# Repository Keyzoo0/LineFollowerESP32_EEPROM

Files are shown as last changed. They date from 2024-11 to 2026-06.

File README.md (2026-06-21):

<div align="center">

# 🤖 Robot Line Follower ESP32 — EEPROM Polinema

**Line follower kompetitif berbasis ESP32 dengan _path-programming on-device_, UI OLED non-blocking, dan 7 profil PID.**
Program lintasan langsung di robot — tanpa laptop, tanpa recompile.









</div>

---

> **🔧 Status:** firmware ini telah di-**refactor total** dari arsitektur _blocking_ menjadi **non-blocking
> (cooperative state machine)** dan dimigrasikan agar **compile bersih di Arduino-ESP32 core v3.x**.
> Diverifikasi dengan `arduino-cli compile` (0 error, 0 warning).

## ✨ Sorotan Fitur

- 🧠 **Path Programming (Plan → Index → Checkpoint)** — sampai **9 plan × 100 langkah**, tiap langkah punya 14 parameter (trigger sensor, aksi, kecepatan 2-fase, PID per-segmen, timer jarak-encoder).
- 🎛️ **UI OLED non-blocking** — navigasi tab/menu responsif, tanpa _freeze_, tanpa konflik antar-menu.
- 📏 **14 sensor IR** via 2× MUX, kalibrasi **auto & manual** + pengaturan sensitivitas.
- 🎚️ **7 profil PID** yang bisa di-tune & dites _live_ di robot.
- 🏁 **Checkpoint resume** + stopwatch waktu tempuh.
- ⚫⚪ **Garis hitam & putih** didukung dalam satu lookup-table, 3 mode follow (center/kanan/kiri).
- 🔋 **Proteksi baterai** (cutoff sebelum start) + indikator persen.
- 🧰 **Tools on-device**: Test Motor, Copy/Mirror Plan, Reset Plan, Set Default, Set Throttle.

---

## 📑 Daftar Isi
1. [Quick Start](#-quick-start)
2. [Hardware](#-hardware)
3. [Arsitektur Non-Blocking](#-arsitektur-non-blocking)
4. [Peta Menu](#-peta-menu)
5. [Path Programming](#-path-programming-planindexcheckpoint)
6. [Profil PID](#-profil-pid)
7. [Apa yang Berubah di Refactor Ini](#-apa-yang-berubah-di-refactor-ini)
8. [Peta Memori](#-peta-memori)
9. [Struktur Proyek](#-struktur-proyek)
10. [Roadmap](#-roadmap)
11. [Kredit & Lisensi](#-kredit--lisensi)

---

## 🚀 Quick Start

<details open>
<summary><b>Build via arduino-cli (cara yang dipakai untuk verifikasi)</b></summary>

```bash
# 1. Pasang core ESP32 v3.x
arduino-cli config add board_manager.additional_urls https://espressif.github.io/arduino-esp32/package_esp32_index.json
arduino-cli core update-index
arduino-cli core install esp32:esp32

# 2. Pasang library
arduino-cli lib install "Adafruit GFX Library" "Adafruit SH110X" "Adafruit PCF8574" "SPIMemory"

# 3. Compile
arduino-cli compile --fqbn esp32:esp32:esp32 LineFollowerESP32_EEPROM

# 4. Upload (ganti /dev/ttyUSB0 sesuai port)
arduino-cli upload  --fqbn esp32:esp32:esp32 -p /dev/ttyUSB0 LineFollowerESP32_EEPROM
```
</details>

<details>
<summary><b>Build via Arduino IDE</b></summary>

1. **Boards Manager** → pasang `esp32 by Espressif` (versi 3.x).
2. **Library Manager** → pasang: Adafruit GFX, Adafruit SH110X, Adafruit PCF8574, SPIMemory.
3. Buka folder `LineFollowerESP32_EEPROM/`, pilih board **ESP32 Dev Module**, lalu Upload.
</details>

> ⚠️ **Setelah flash pertama**, jalankan menu **Settings → Set Default** sekali untuk menginisialisasi
> layout memori baru (`VAL_INDEX` kini 100). Lalu **Calib Sensor → Auto** untuk kalibrasi lintasan.

---

## 🔩 Hardware

| Subsistem | Komponen | Pin / Alamat |
|---|---|---|
| **MCU** | ESP32 (240 MHz) | — |
| **Sensor garis** | 14× IR analog via 2× MUX 8-kanal (7 kiri + 7 kanan) | ADC `32` (kiri), `35` (kanan); selektor `13/14/15` |
| **Driver motor** | H-bridge (BTS7960), PWM LEDC 15 kHz / 8-bit | Kiri `26/27` · Kanan `17/16` |
| **Encoder** | 2× rotary quadrature (CPR 208, roda Ø17 mm) | Kiri `33/25` · Kanan `39/36` |
| **Display** | OLED SH1106 128×64 I²C | `0x3C` |
| **Tombol** | 6 tombol via PCF8574 (I²C expander) | `0x27` |
| **Memori lintasan** | SPI Flash Winbond 4MB (SPIMemory) | CS `5` |
| **Memori konfigurasi** | EEPROM emulasi 1 KB | — |
| **Baterai** | ADC + divider 10k/3.3k, filter EMA, cutoff 11.8 V | `34` |
| **LED status** | indikator tulis memori | `12` |

> PCB (KiCad) & model 3D tersedia di folder [`Electrical/`](Electrical) dan [`3d Model/`](3d%20Model).

---

## 🧩 Arsitektur Non-Blocking

Versi lama menjebak eksekusi di `while(1)` tiap menu (blocking) + tombol _busy-wait_ + state global dipakai
bersama → tidak responsif & sering konflik antar-menu. Versi ini memakai **loop kooperatif**:

```mermaid
flowchart LR
    L([loop]) --> I[inputUpdate<br/>baca 6 tombol sekali<br/>edge + auto-repeat]
    I --> H[uiHandle<br/>logika layar aktif]
    H --> F{sudah 33 ms?}
    F -- ya --> R[uiRender<br/>1x lcd.display per frame]
    F -- tidak --> L
    R --> L
```

**3 pilar yang menghilangkan blocking & konflik:**

| Pilar | Sebelum | Sesudah |
|---|---|---|
| **Input** | `touchUp()` _busy-wait_ menunggu tombol dilepas | `inputUpdate()` non-blocking → event `PRESS / HOLD / RELEASE` (debounce + auto-repeat berbasis `millis()`) |
| **Render** | `clearDisplay()/display()` berserak di tiap layar | satu `lcd.display()` per frame (~30 fps) |
| **State** | global `selectSet/countMenu/halIdx` dipakai bersama | tiap layar punya **struct state lokal** + **screen stack** (push/pop) |

Navigasi antar-layar memakai state machine + stack:

```mermaid
stateDiagram-v2
    [*] --> HOME
    HOME --> MENU: OK
    HOME --> SETINDEX: Set Plan
    HOME --> CHECKPOINT
    HOME --> CALIB
    HOME --> RACE: RUN (mode C)
    HOME --> TUNEPID: RUN (mode F)
    MENU --> SETTINGS
    MENU --> TUNEPID
    MENU --> TESTMOTOR
    MENU --> COPYMIRROR
    MENU --> RESETPLAN
    SETINDEX --> ADDREMOVE
    SETTINGS --> SETDEFAULT
    SETTINGS --> THROTTLE
    RACE --> RACE_RESULT
    RACE_RESULT --> HOME
```

> 🏁 **Mode balapan** sengaja tetap _tight loop_ real-time (deterministik untuk kontrol), namun tombol
> abort dibaca non-blocking dan **semua timing pakai `millis()`** (tanpa `delay()`), jadi abort tetap responsif.

---

## 🗺️ Peta Menu

<details open>
<summary><b>Pohon menu lengkap</b></summary>

```
HOME ── UP/DOWN pindah widget · RUN = mulai ──────────────────────────
├─ Mode C/F        C=Balapan, F=Tune PID   ·  OK → MAIN MENU
├─ Set Plan        pilih plan (1–9)         ·  OK → SET INDEX
├─ Normal Speed    ±5
├─ CHKPNT          OK → CHECKPOINT
└─ CALSEN          OK → CALIB SENSOR

MAIN MENU ── UP/DOWN · RUN = back ────────────────────────────────────
├─ Set Plan          OK → SET INDEX
├─ Calib Sensor      +:Auto   -:Manual
├─ Tuning PID        OK → TUNE PID
├─ Test Motor        OK → TEST MOTOR
├─ Copy Mirror Plan  OK → COPY/MIRROR
├─ Delete Plan       OK → RESET PLAN
└─ Settings          OK → SETTINGS (Set Default · Set Throttle)

SET INDEX ── editor langkah (list datar, 15 baris) ───────────────────
   Index · Trig SLog · Trig Logic · Action · Speed L/R · Act Delay ·
   PID Prof · Speed A · Timer A · Mode TIM · Speed B · Timer B ·
   UsedSens · FL Mode      (OK di baris "Index" → ADD/REMOVE langkah)
```
</details>

**Tombol:** `OK` pilih/masuk · `UP/DOWN` navigasi · `+ / -` ubah nilai (tahan = auto-repeat) · `RUN` kembali/mulai.

---

## 🧠 Path Programming (Plan/Index/Checkpoint)

Robot menjalankan **program lintasan** yang tersimpan, bukan sekadar mengikuti garis.

- **Plan** = satu lintasan penuh (ada **9** plan).
- **Index** = satu langkah dalam plan (ada **100** langkah/plan). Tiap langkah menyimpan:

| Parameter | Fungsi |
|---|---|
| `Trig SLog` + `Trig Logic` | **Pemicu**: pola sensor + logika `OR / AND / TIM / XOR` |
| `Action` | aksi saat terpicu: `STOP/FORWARD/LEFT/RIGHT/BACKWARD/PICK/DROP/TLEFT/TRIGHT/FAN` |
| `Speed L/R` + `Act Delay` | kecepatan & durasi aksi |
| `Speed A/B` + `Timer A/B` | **2 fase kecepatan** dengan ramp berbeda |
| `Mode TIM` | sumber timer: waktu `mS` atau **jarak encoder** `CmR/CmL` |
| `PID Prof` | profil PID per-segmen (Normal..Profil 6) |
| `UsedSens` | masking sensor pinggir (All / Ignore 1–3 sisi) |
| `FL Mode` | sisi garis: `FLC` center · `FLR` kanan · `FLL` kiri |

- **Checkpoint** = titik _resume_; robot bisa lanjut balapan dari langkah tertentu (8 CP/plan).

```mermaid
flowchart TD
    S[start] --> RD[baca sensor]
    RD --> TR{pemicu langkah<br/>terpenuhi?}
    TR -- tidak --> PID[ikuti garis PID<br/>normalSpeed] --> RD
    TR -- ya --> ACT[eksekusi Action] --> A[fase A: ramp ke Speed A<br/>selama Timer A]
    A --> B[fase B: ramp ke Speed B<br/>selama Timer B]
    B --> ST{langkah == stop?}
    ST -- tidak --> NX[langkah++] --> RD
    ST -- ya --> F([selesai: tampil waktu])
```

---

## 🎚️ Profil PID

7 profil tersimpan di EEPROM, di-tune lewat **Tuning PID** (+ uji _live_ "Coba PID"):

| Profil | Kp | Ki | Kd | Target v |
|:---:|:--:|:--:|:--:|:---:|
| Normal | 3.0 | 0.00 | 10 | 50 |
| Profil 1 | 7.0 | 0.02 | 12 | 80 |
| Profil 2 | 7.0 | 0.02 | 15 | 100 |
| Profil 3 | 7.4 | 0.04 | 35 | 120 |
| Profil 4 | 7.4 | 0.04 | 40 | 140 |
| Profil 5 | 7.4 | 0.04 | 50 | 160 |
| Profil 6 | 7.4 | 0.04 | 60 | 180 |

Hukum kontrol: `move = error·Kp + ΣError·Ki + Δerror·Kd` → `kiri = v − move`, `kanan = v + move` (clamp ±255).

---

## 🔄 Apa yang Berubah di Refactor Ini

<details>
<summary><b>🐞 Bug yang diperbaiki</b></summary>

| # | Bug | Perbaikan |
|---|-----|---|
| 1 | `VAL_INDEX=50` tapi UI memakai index 0–99 → **buffer overflow** | dinaikkan ke **100** + serialisasi flash diperbarui |
| 2 | Hanya 5 dari 9 plan dibaca saat boot (`readIdx` loop `<5`) | dimuat penuh `< VAL_PLAN` |
| 3 | `analogReadResolution(8)` vs kalibrasi skala 1023 | disamakan ke **10-bit** (battery ikut diperbaiki ÷1023) |
| 4 | `accelTA/accelTB` diatur tapi tak dipakai | kini **benar-benar dipakai** sebagai step ramp fase A/B |
| 5 | Transfer Plan tak terjangkau / stub | dihapus dari menu (out-of-scope) |
| 6 | `guiTestMotor` `speedsR == 255` (operator salah) | ditulis ulang dengan clamp benar |
| 7 | Duplikasi `struct Plan/CP` global (~15 KB) + bug sinkronisasi | dihapus, serialisasi via blob transien |

</details>

<details>
<summary><b>⚙️ Migrasi Arduino-ESP32 v3.x (LEDC)</b></summary>

| Lama (v2.x) | Baru (v3.x) |
|---|---|
| `ledcSetup(ch, freq, res)` + `ledcAttachPin(pin, ch)` | `ledcAttach(pin, freq, res)` |
| `ledcWrite(ch, duty)` | `ledcWrite(pin, duty)` |

Terisolasi di `motor.ino` — logika kontrol tidak berubah.
</details>

---

## 💾 Peta Memori

**EEPROM (1 KB)** — konfigurasi: home (0–3), sensitivity (4), max/min sensor (6–61), kalibrasi (62–89),
Kp/Ki/Kd (90–110), accel (111–112).

**SPI Flash 4MB** — lintasan: 9 plan × 1700 B + 9 checkpoint × 32 B ≈ **15.6 KB** (muat dalam `eraseBlock32K`).
Serialisasi memakai **blob transien** — tidak ada duplikasi RAM.

---

## 📂 Struktur Proyek

| Lapisan | File | Peran |
|---|---|---|
| **Entry** | `LineFollowerESP32_EEPROM.ino` | `setup()` + `loop()` (input → handle → render) |
| **Data** | `data.h`, `storage.ino` | konfigurasi, plan, checkpoint, save/load |
| **Input** | `input.h`, `input.ino` | tombol non-blocking (PCF8574) |
| **UI** | `ui.h`, `ui.ino` | state machine + dispatcher |
| **Layar** | `screens_main.ino`, `screens_index.ino`, `screens_tools.ino` | semua menu |
| **Kontrol** | `PID.ino`, `sensor.ino`, `motor.ino`, `encoder.ino`, `race.ino` | follow line + balapan |
| **Display** | `oled.h`, `oled.ino` | SH1106 + bitmap + helper gambar |
| **Util** | `timer.h` | stopwatch millis |

---

## 🛣️ Roadmap

Fitur berikut sengaja **di-tunda** (hardware belum ada / out-of-scope) agar fokus pada line follower:

- [ ] Transfer Plan (robot ↔ robot)
- [ ] Gripper & Fan (aksi `PICK/DROP/FAN` kini no-op)
- [ ] Setting Encoder (PID kecepatan)
- [ ] Wi-Fi + OTA Update
- [ ] Mode Transporter

---

## 🙏 Kredit & Lisensi

Dirancang oleh **Komunitas EEPROM Polinema** (tim G14/G15).
Refactor arsitektur non-blocking & migrasi core v3.x.

Lisensi **MIT** © 2024 [Keyzoo0](https://github.com/Keyzoo0) — lihat [LICENSE](LICENSE).

<div align="center">

⭐ _Kalau proyek ini membantu, kasih bintang ya!_ ⭐

</div>

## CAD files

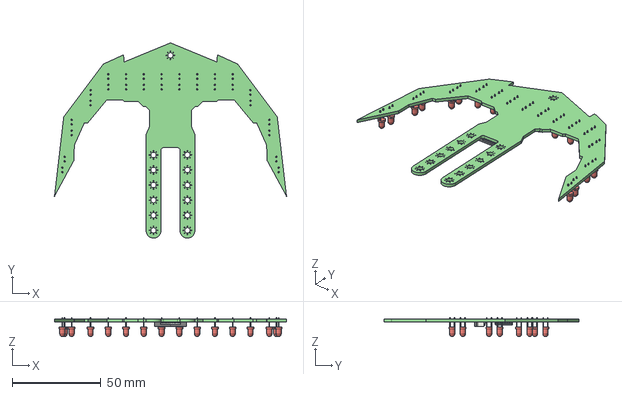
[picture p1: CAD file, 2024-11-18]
Electrical/Sensor_V2.1_2/Sensor_V2.1.step
130.6 x 109.9 x 10.8 mm
Sensor_V2.1 PCB

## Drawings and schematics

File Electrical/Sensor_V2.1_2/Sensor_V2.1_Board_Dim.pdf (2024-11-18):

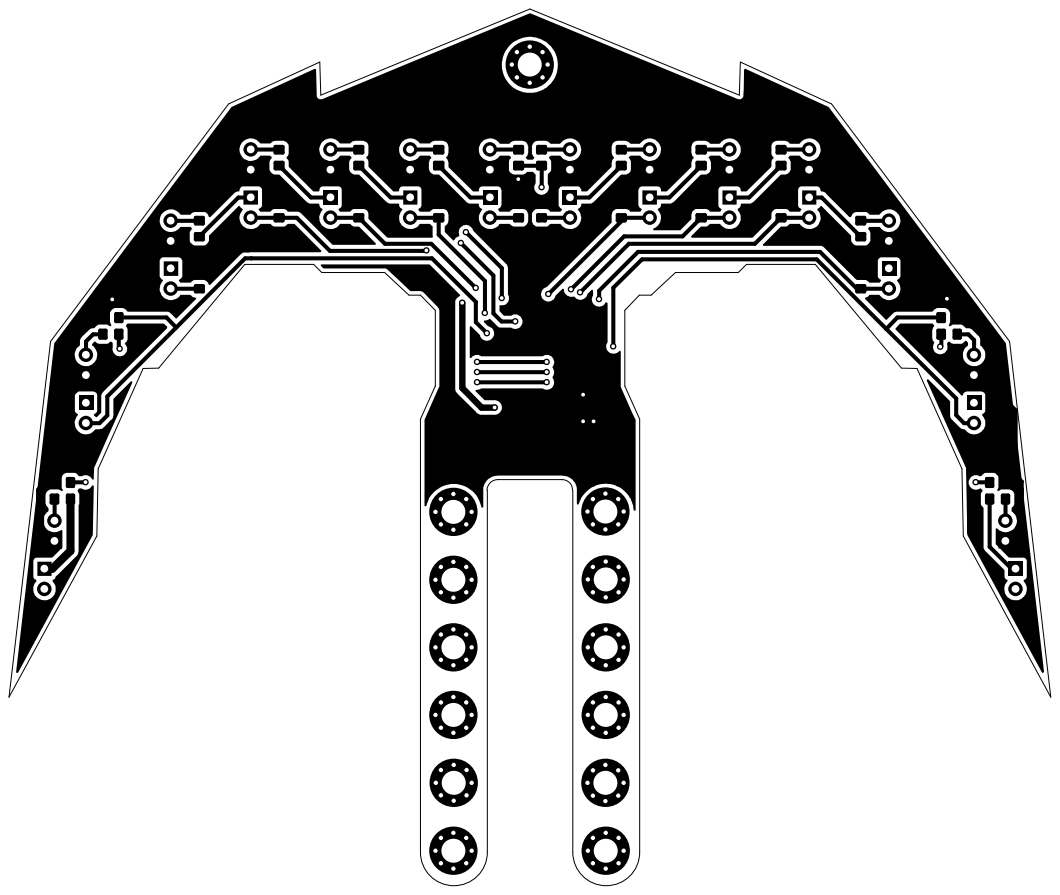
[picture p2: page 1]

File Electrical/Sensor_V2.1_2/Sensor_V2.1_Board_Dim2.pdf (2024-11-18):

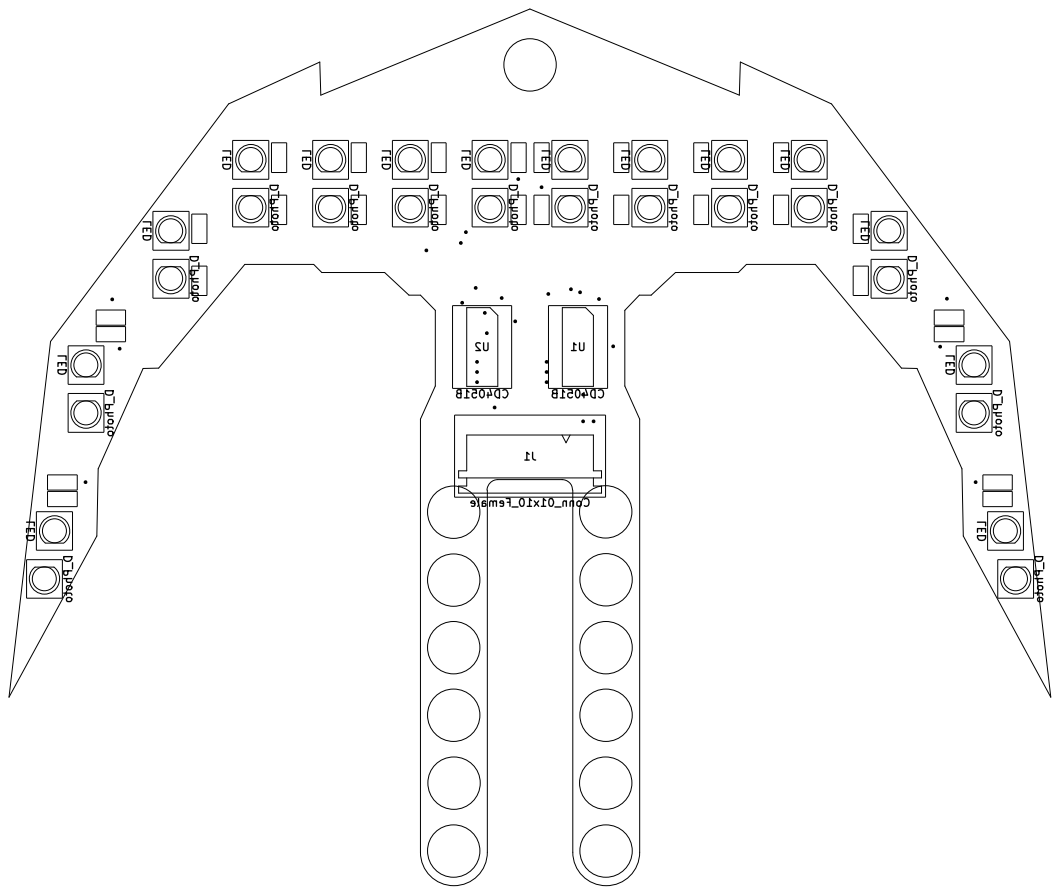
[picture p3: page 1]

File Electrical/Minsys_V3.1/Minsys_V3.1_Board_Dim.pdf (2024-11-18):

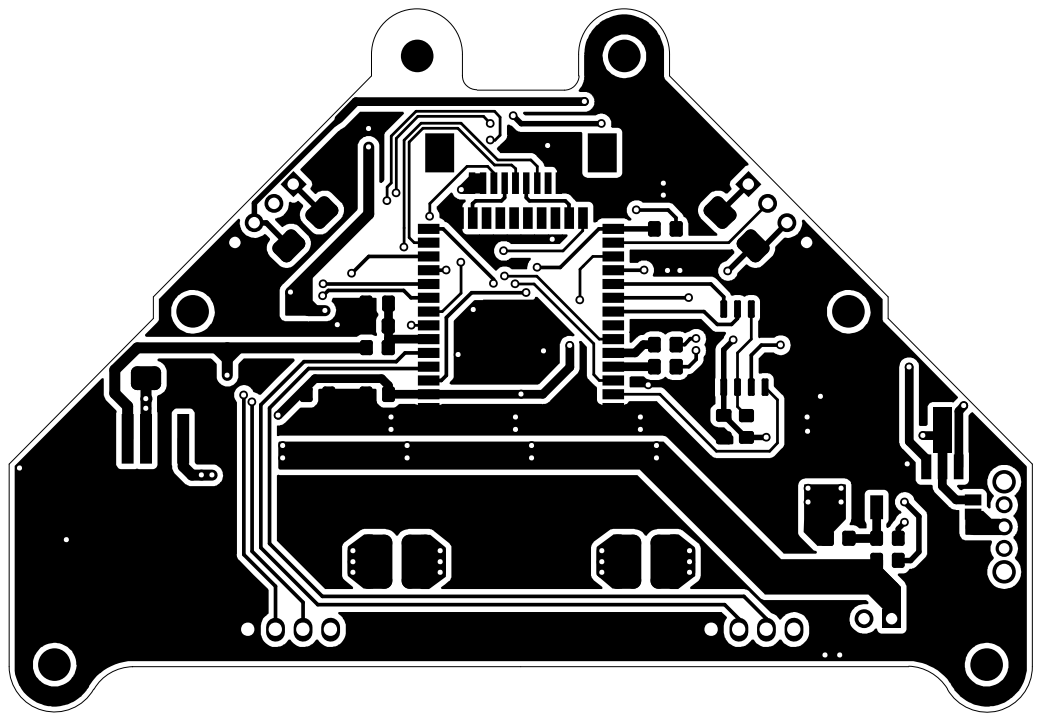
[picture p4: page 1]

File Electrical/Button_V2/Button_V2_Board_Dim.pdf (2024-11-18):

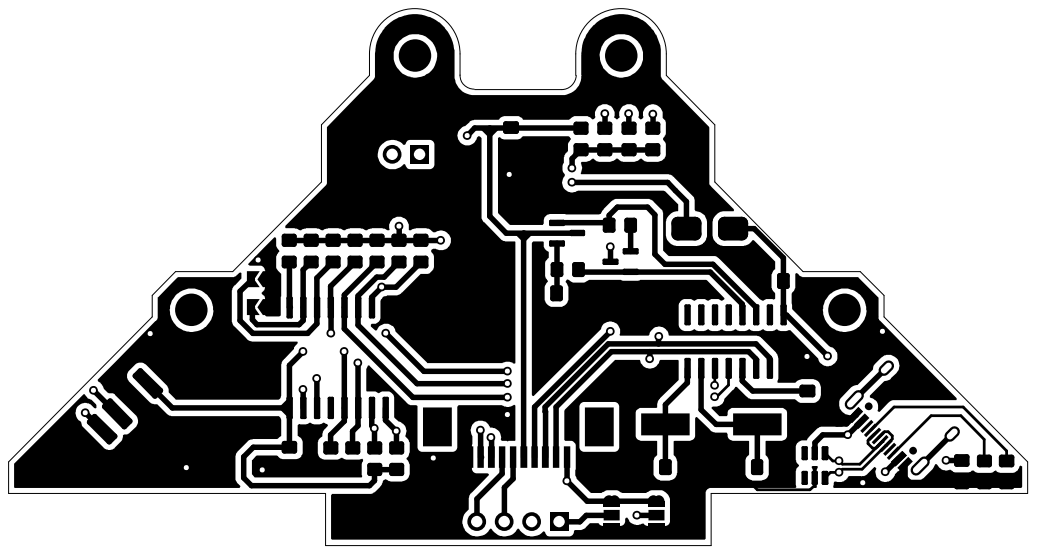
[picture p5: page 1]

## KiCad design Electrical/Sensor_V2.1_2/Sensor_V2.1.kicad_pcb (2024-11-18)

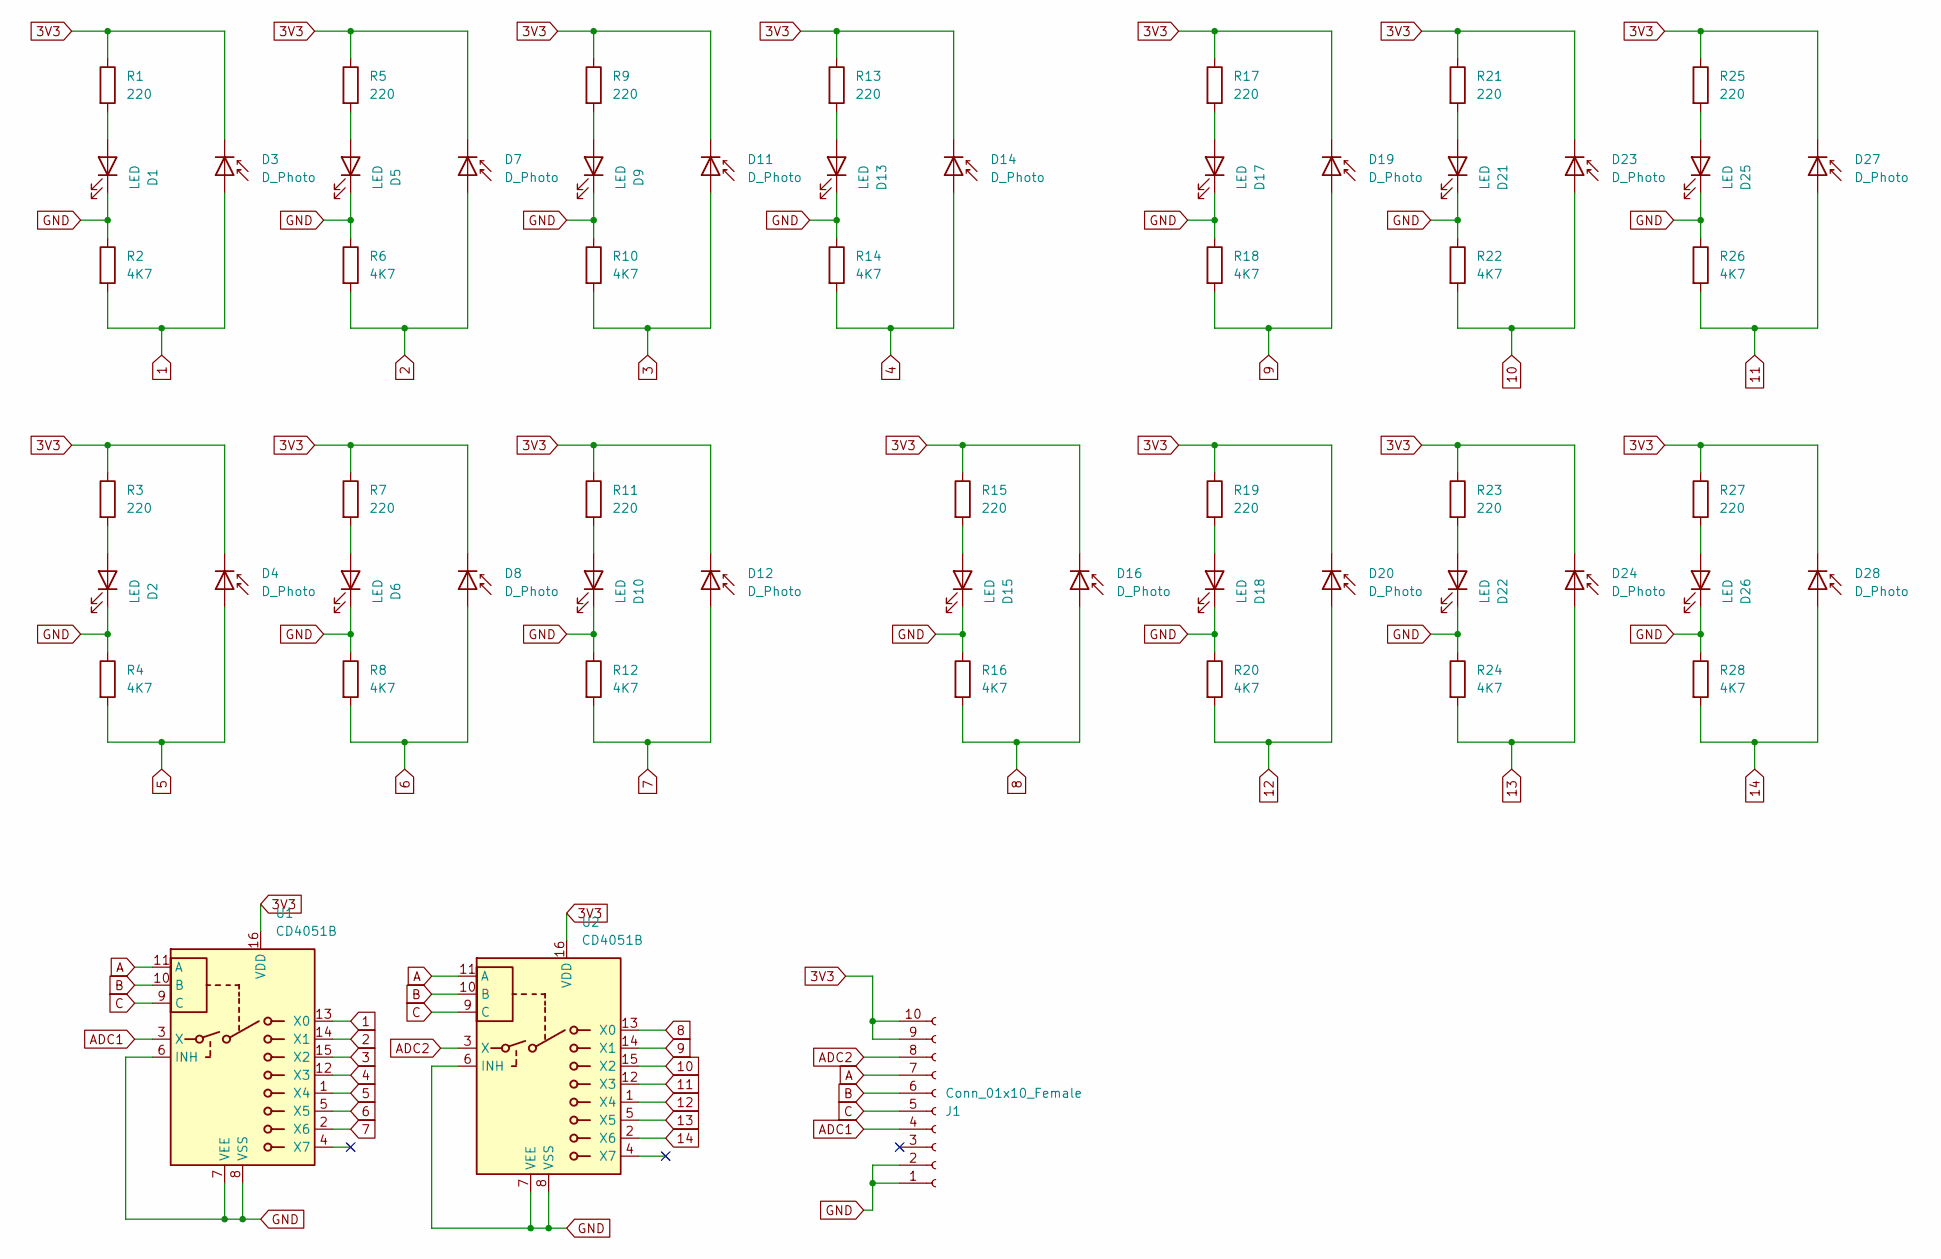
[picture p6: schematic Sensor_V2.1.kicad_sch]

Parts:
D1, D2, D5, D6, D9, D10, D13, D15, D17, D18, D21, D22, D25, D26: LED; LED_D3.0mm
D3, D4, D7, D8, D11, D12, D14, D16, D19, D20, D23, D24, D27, D28: D_Photo; LED_D3.0mm
J1: Conn_01x10_Female; TE_1-84952-0_1x10-1MP_P1.0mm_Horizontal
R1, R3, R5, R7, R9, R11, R13, R15, R17, R19, R21, R23, R25, R27: 220; R_0805_2012Metric_Pad1.20x1.40mm_HandSolder
R2, R4, R6, R8, R10, R12, R14, R16, R18, R20, R22, R24, R26, R28: 4K7; R_0805_2012Metric_Pad1.20x1.40mm_HandSolder
U1, U2: CD4051B; SOIC-16_3.9x9.9mm_P1.27mm

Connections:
1: D3.2 (A), R2.2, U1.13 (X0)
2: D7.2 (A), R6.2, U1.14 (X1)
3: D11.2 (A), R10.2, U1.15 (X2)
3V3: D3.1 (K), D4.1 (K), D7.1 (K), D8.1 (K), D11.1 (K), D12.1 (K), D14.1 (K), D16.1 (K), D19.1 (K), D20.1 (K), D23.1 (K), D24.1 (K), D27.1 (K), D28.1 (K), J1.9, J1.10, R1.1, R3.1, R5.1, R7.1, R9.1, R11.1, R13.1, R15.1, R17.1, R19.1, R21.1, R23.1, R25.1, R27.1, U1.16 (VDD), U2.16 (VDD)
4: D14.2 (A), R14.2, U1.12 (X3)
5: D4.2 (A), R4.2, U1.1 (X4)
6: D8.2 (A), R8.2, U1.5 (X5)
7: D12.2 (A), R12.2, U1.2 (X6)
8: D16.2 (A), R16.2, U2.13 (X0)
9: D19.2 (A), R18.2, U2.14 (X1)
10: D23.2 (A), R22.2, U2.15 (X2)
11: D27.2 (A), R26.2, U2.12 (X3)
12: D20.2 (A), R20.2, U2.1 (X4)
13: D24.2 (A), R24.2, U2.5 (X5)
14: D28.2 (A), R28.2, U2.2 (X6)
A: J1.7, U1.11 (A), U2.11 (A)
ADC1: J1.4, U1.3 (X)
ADC2: J1.8, U2.3 (X)
B: J1.6, U1.10 (B), U2.10 (B)
C: J1.5, U1.9 (C), U2.9 (C)
GND: D1.1 (K), D2.1 (K), D5.1 (K), D6.1 (K), D9.1 (K), D10.1 (K), D13.1 (K), D15.1 (K), D17.1 (K), D18.1 (K), D21.1 (K), D22.1 (K), D25.1 (K), D26.1 (K), J1.1, J1.2, R2.1, R4.1, R6.1, R8.1, R10.1, R12.1, R14.1, R16.1, R18.1, R20.1, R22.1, R24.1, R26.1, R28.1, U1.6 (INH), U1.7 (VEE), U1.8 (VSS), U2.6 (INH), U2.7 (VEE), U2.8 (VSS)
unnamed: D1.2 (A), R1.2
unnamed: D2.2 (A), R3.2
unnamed: D5.2 (A), R5.2
unnamed: D6.2 (A), R7.2
unnamed: D9.2 (A), R9.2
unnamed: D10.2 (A), R11.2
unnamed: D13.2 (A), R13.2
unnamed: D15.2 (A), R15.2
unnamed: D17.2 (A), R17.2
unnamed: D18.2 (A), R19.2
unnamed: D21.2 (A), R21.2
unnamed: D22.2 (A), R23.2
unnamed: D25.2 (A), R25.2
unnamed: D26.2 (A), R27.2

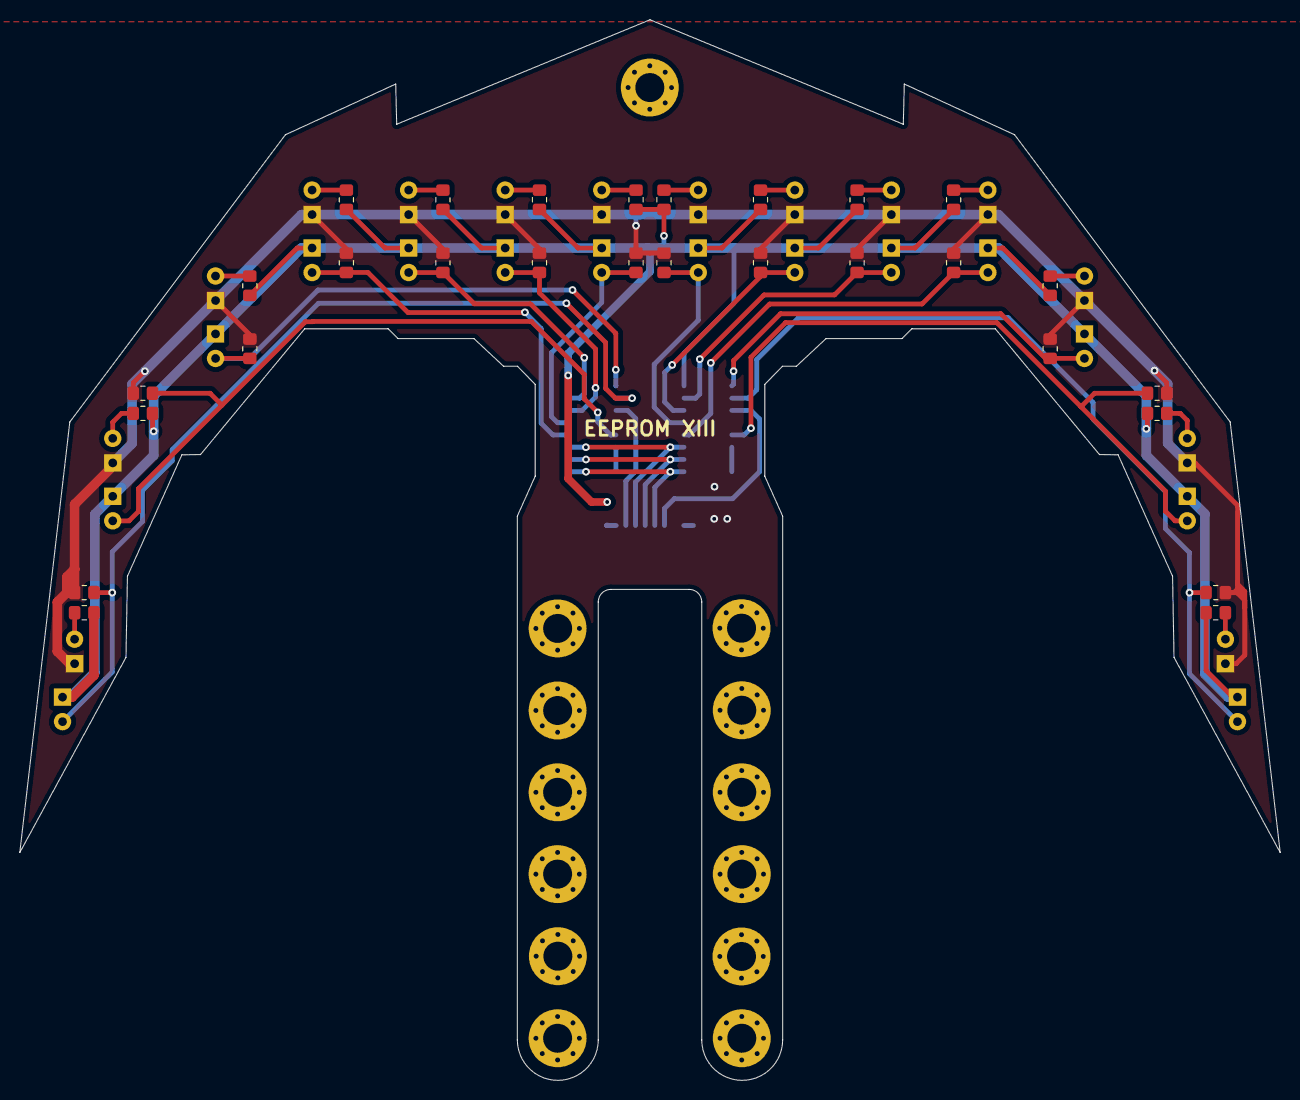
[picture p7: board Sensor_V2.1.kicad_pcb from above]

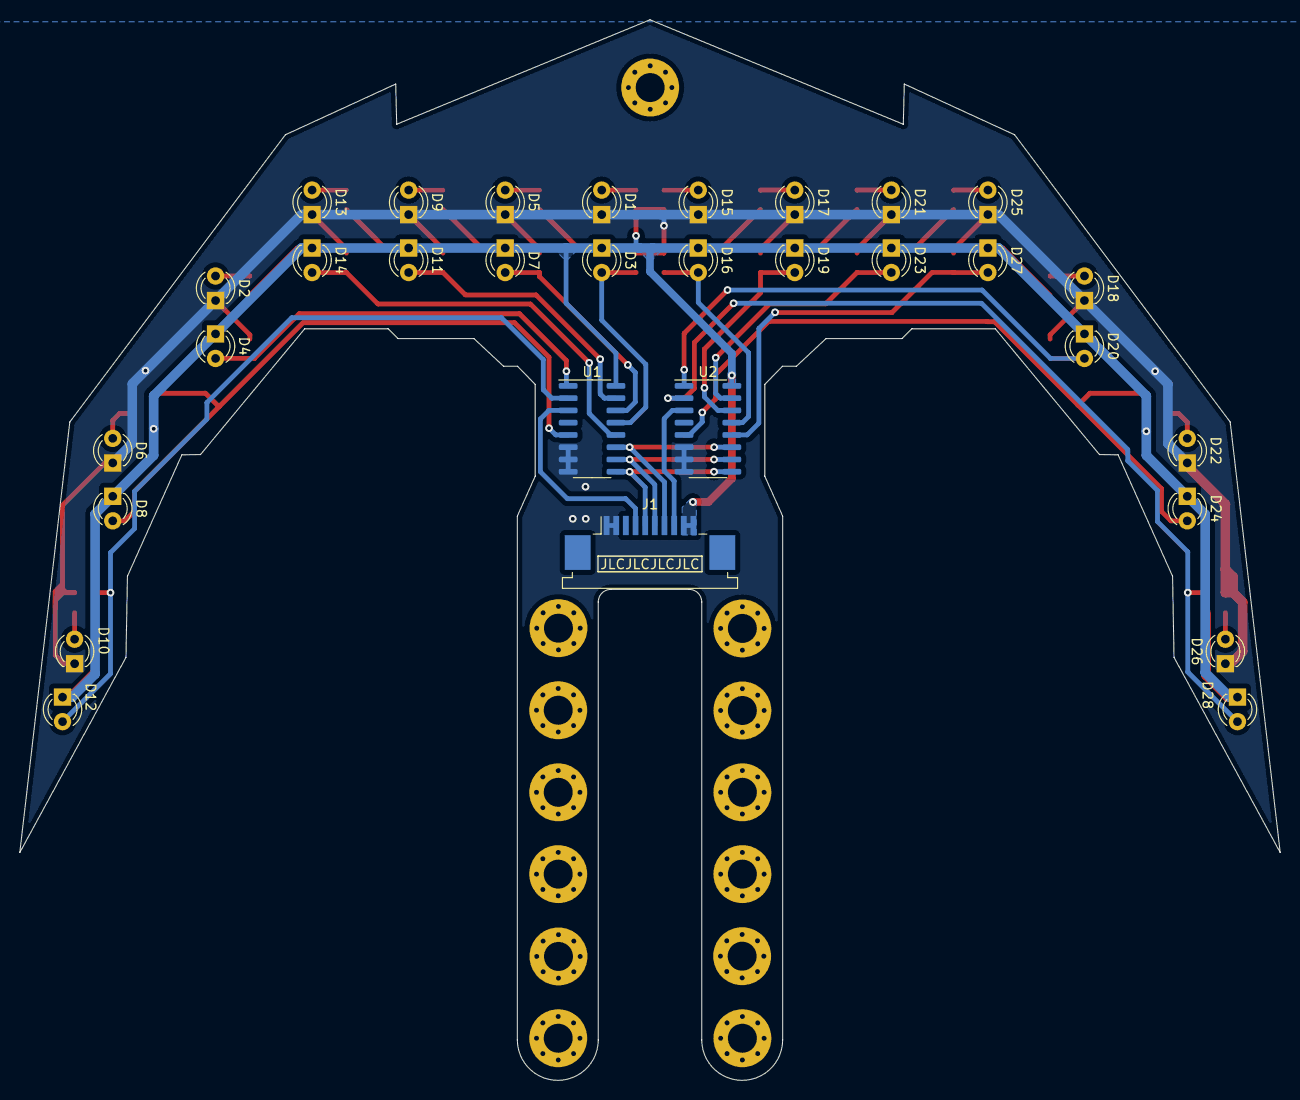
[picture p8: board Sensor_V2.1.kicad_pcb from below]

Board: 2 copper layers, 130.6 x 109.9 mm, 72 parts (31 on the bottom side), 35 nets.

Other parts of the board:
H1, H4, H5, H6, H7, H8, H10, H12, H13, H14, H15, H17, H21: MountingHole; MountingHole_3mm_Pad_Via

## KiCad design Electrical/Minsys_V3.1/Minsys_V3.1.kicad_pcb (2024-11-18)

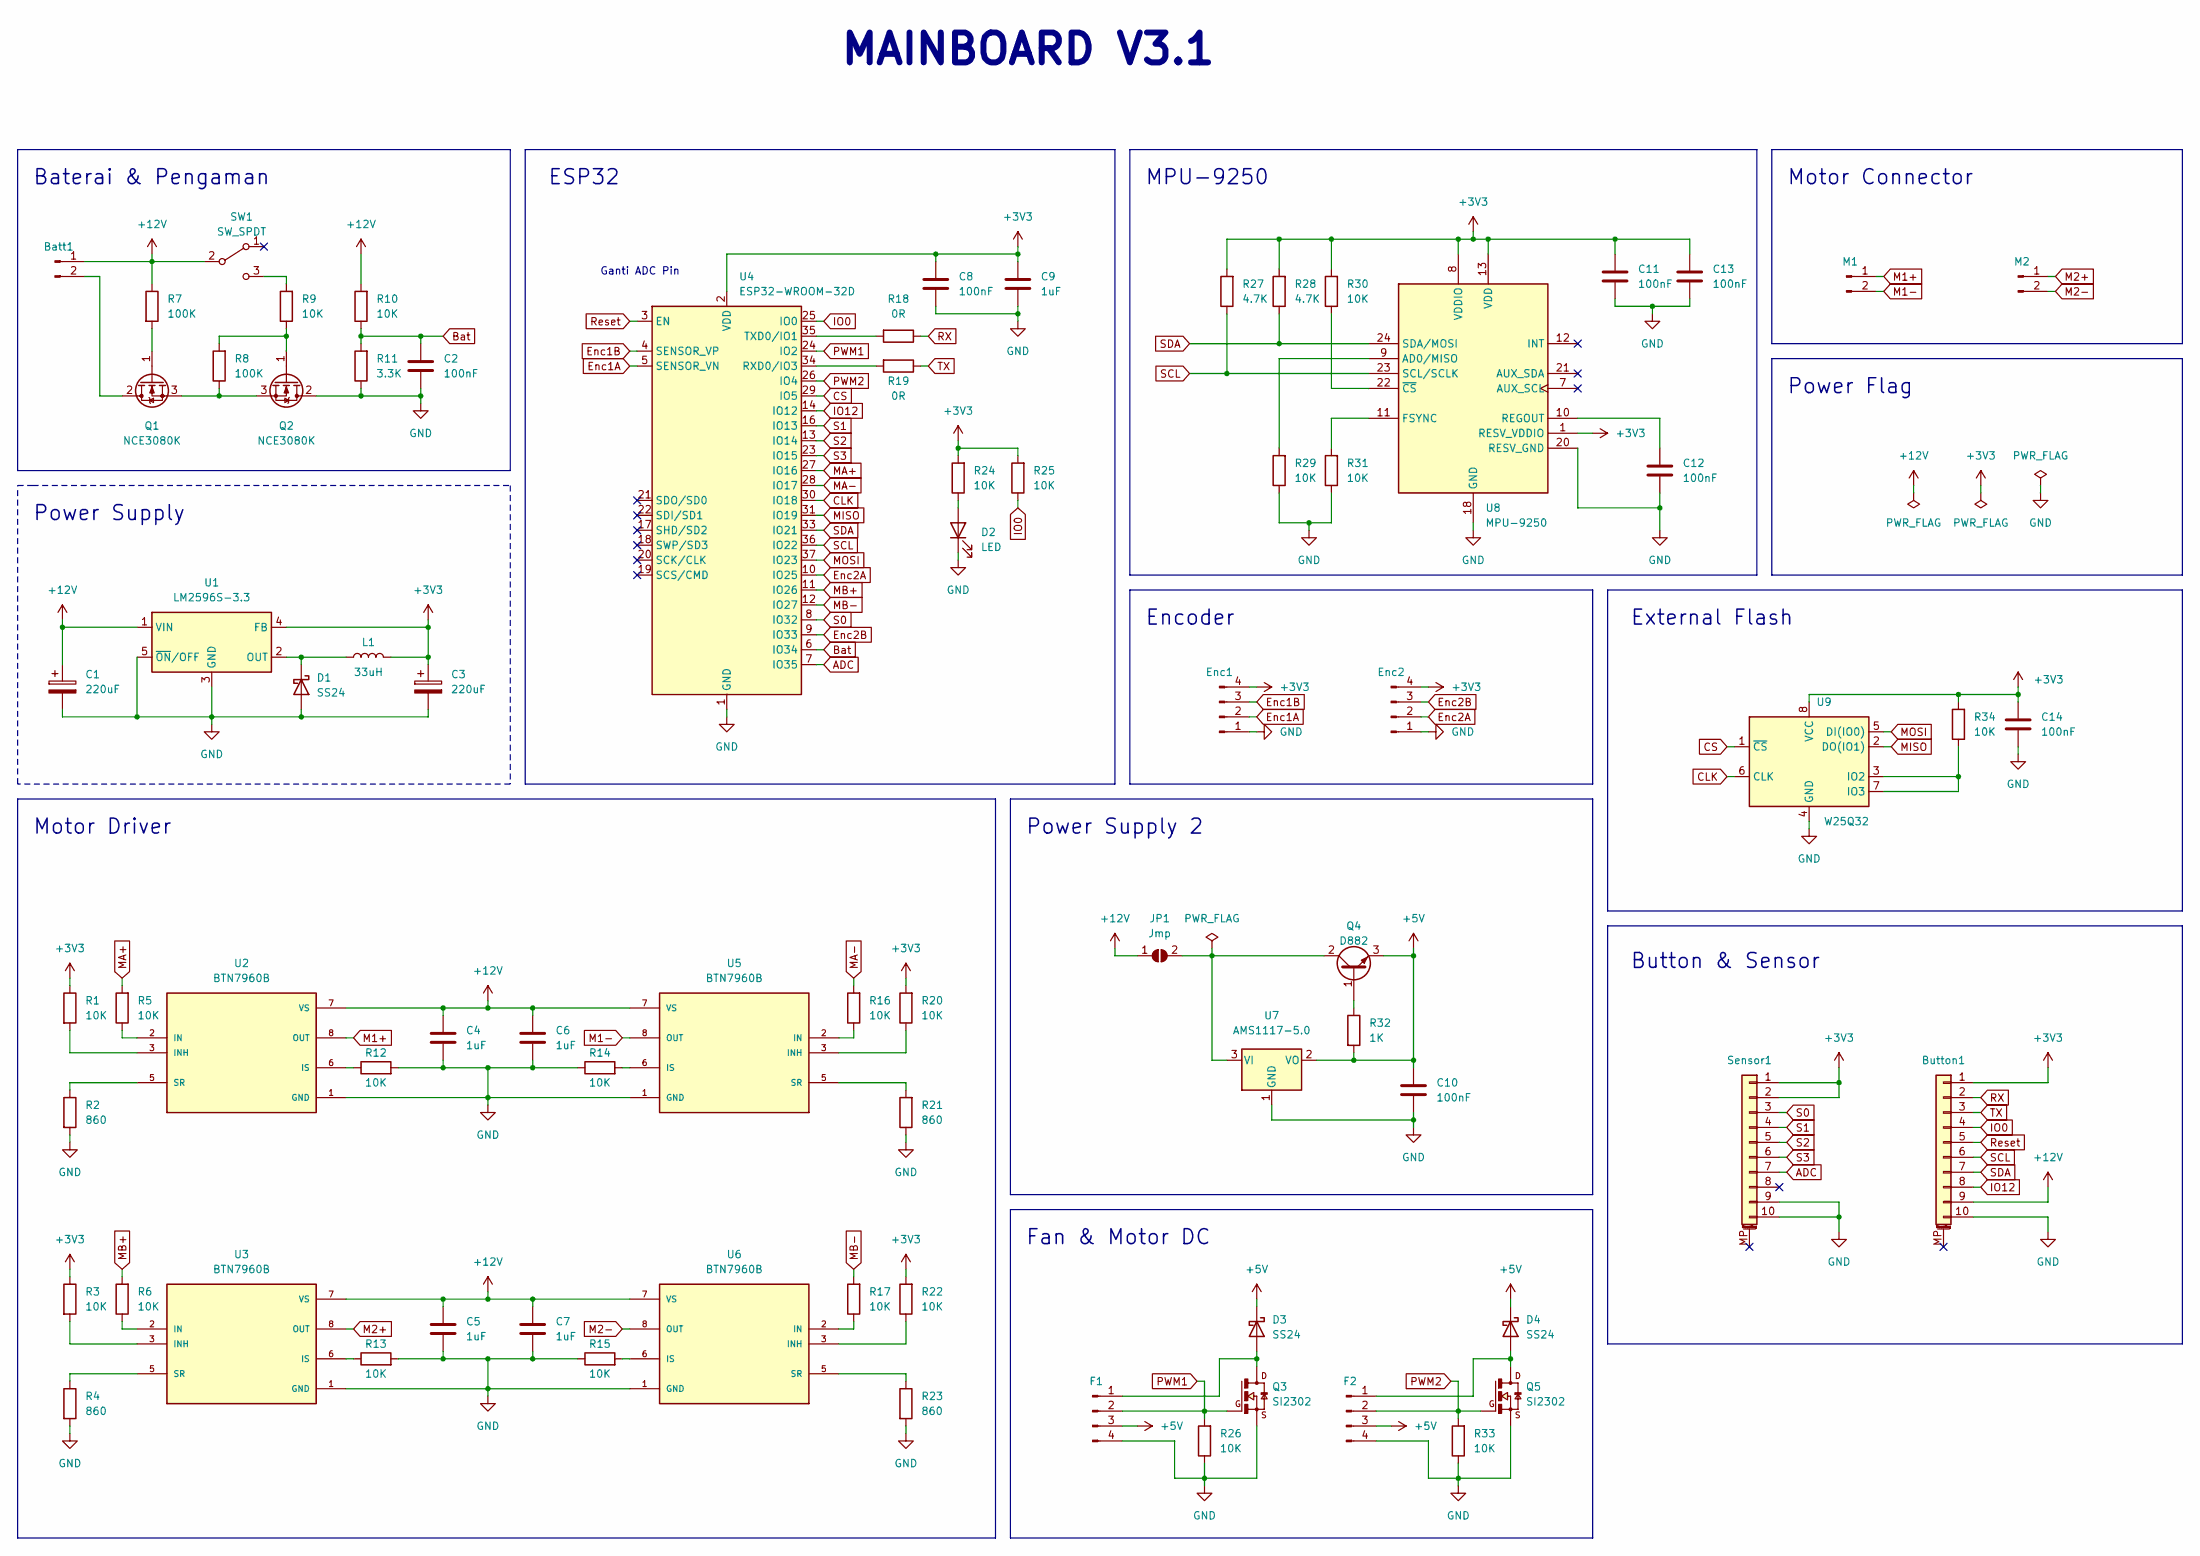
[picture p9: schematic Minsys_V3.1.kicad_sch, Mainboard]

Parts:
Batt1: Conn_01x02_Male; PinHeader_1x02_P2.54mm_Vertical
Button1: Conn_01x10_MountingPin; TE_1-84952-0_1x10-1MP_P1.0mm_Horizontal
C1, C3: 220uF; CP_Elec_6.3x5.4
C2, C8, C10, C11, C12, C13, C14: 100nF; C_0805_2012Metric_Pad1.18x1.45mm_HandSolder
C4, C5, C6, C7, C9: 1uF; C_0805_2012Metric_Pad1.18x1.45mm_HandSolder
D1, D3, D4: SS24; DO_214
D2: LED; LED_0805_2012Metric_Pad1.15x1.40mm_HandSolder
Enc1, Enc2: Conn_01x04_Male
F1, F2: Conn_01x04_Male; PinHeader_1x04_P2.54mm_Vertical
JP1: Jmp; SolderJumper-2_P1.3mm_Open_Pad1.0x1.5mm
L1: 33uH; L_12x12mm_H6mm
M1, M2: Motor_Pad; Motor_Connetor
Q1, Q2: NCE3080K; TO-252-2
Q3, Q5: SI2302; SOT-23
Q4: D882; SOT-89-3_Handsoldering
R1, R3, R5, R6, R9, R10, R12, R13, R14, R15, R16, R17, R20, R22, R24, R25, R26, R29, R30, R31, R33, R34: 10K; R_0805_2012Metric_Pad1.20x1.40mm_HandSolder
R2, R4, R21, R23: 860; R_0805_2012Metric_Pad1.20x1.40mm_HandSolder
R7, R8: 100K; R_0805_2012Metric_Pad1.20x1.40mm_HandSolder
R11: 3.3K; R_0805_2012Metric_Pad1.20x1.40mm_HandSolder
R18, R19: 0R; R_0805_2012Metric_Pad1.20x1.40mm_HandSolder
R27, R28: 4.7K; R_0805_2012Metric_Pad1.20x1.40mm_HandSolder
R32: 1K; R_0805_2012Metric_Pad1.20x1.40mm_HandSolder
SW1: SW_SPDT; SPDT_Type_2
Sensor1: Conn_01x10_MountingPin; TE_1-84952-0_1x10-1MP_P1.0mm_Horizontal
U1: LM2596S-3.3; TO-263-5_TabPin3
U2, U3, U5, U6: BTN7960B; Infineon_PG-TO-220-7Lead_TabPin8; PARTREV 1.0
U4: ESP32-WROOM-32D; ESP32-WROOM-32
U7: AMS1117-5.0; SOT-223-3_TabPin2
U8: MPU-9250; InvenSense_QFN-24_3x3mm_P0.4mm
U9: W25Q32; SOIC-8_5.23x5.23mm_P1.27mm; PARTREV F

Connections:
+3V3: Button1.1, C3.1, C8.1, C9.1, C11.1, C13.1, C14.1, Enc1.4, Enc2.4, L1.2, R1.1, R3.1, R20.2, R22.2, R24.2, R25.2, R27.2, R28.2, R30.2, R34.2, Sensor1.1, Sensor1.2, U1.4 (FB), U4.2 (VDD), U8.1 (RESV_VDDIO), U8.8 (VDDIO), U8.13 (VDD), U9.8 (VCC)
+5V: C10.1, D3.1 (K), D4.1 (K), F1.3, F2.3, Q4.3, R32.2, U7.2 (VO)
+12V: Batt1.1, Button1.9, C1.1, C4.1, C5.1, C6.1, C7.1, JP1.1 (A), R7.1, R10.2, SW1.2 (B), U1.1 (VIN), U2.7 (VS), U3.7 (VS), U5.7 (VS), U6.7 (VS)
ADC: Sensor1.7, U4.7 (IO35)
Bat: C2.1, R10.1, R11.2, U4.6 (IO34)
CLK: U4.30 (IO18), U9.6 (CLK)
CS: U4.29 (IO5), U9.1 (~CS)
Enc1A: Enc1.2, U4.5 (SENSOR_VN)
Enc1B: Enc1.3, U4.4 (SENSOR_VP)
Enc2A: Enc2.2, U4.10 (IO25)
Enc2B: Enc2.3, U4.9 (IO33)
GND: Button1.10, C1.2, C2.2, C3.2, C4.2, C5.2, C6.2, C7.2, C8.2, C9.2, C10.2, C11.2, C12.2, C13.2, C14.2, D1.2 (A), D2.1 (K), Enc1.1, Enc2.1, F1.4, F2.4, Q2.2 (D), Q3.2, Q5.2, R2.2, R4.2, R11.1, R12.2, R13.2, R14.1, R15.1, R21.1, R23.2, R26.1, R29.1, R31.1, R33.1, Sensor1.9, Sensor1.10, U1.3 (GND), U1.5 (~ON/OFF), U2.1 (GND), U3.1 (GND), U4.1 (GND), U4.15 (GND), U4.38 (GND), U4.39 (GND), U5.1 (GND), U6.1 (GND), U7.1 (GND), U8.18 (GND), U8.20 (RESV_GND), U9.4 (GND)
IO0: Button1.4, R25.1, U4.25 (IO0)
IO12: Button1.8, U4.14 (IO12)
M1+: M1.1, U2.4 (OUT), U2.8 (OUT)
M1-: M1.2, U5.4 (OUT), U5.8 (OUT)
M2+: M2.1, U3.4 (OUT), U3.8 (OUT)
M2-: M2.2, U6.4 (OUT), U6.8 (OUT)
MA+: R5.2, U4.27 (IO16)
MA-: R16.2, U4.28 (IO17)
MB+: R6.2, U4.11 (IO26)
MB-: R17.2, U4.12 (IO27)
MISO: U4.31 (IO19), U9.2 (DO(IO1))
MOSI: U4.37 (IO23), U9.5 (DI(IO0))
unnamed: Batt1.2, Q1.2 (D)
unnamed: C12.1, U8.10 (REGOUT)
unnamed: D1.1 (K), L1.1, U1.2 (OUT)
unnamed: D2.2 (A), R24.1
unnamed: D3.2 (A), F1.1, Q3.3
unnamed: D4.2 (A), F2.1, Q5.3
unnamed: JP1.2 (B), Q4.2, U7.3 (VI)
unnamed: Q1.1 (G), R7.2
unnamed: Q1.3 (S), Q2.3 (S), R8.1
unnamed: Q2.1 (G), R8.2, R9.1
unnamed: Q4.1, R32.1
unnamed: R1.2, U2.3 (INH)
unnamed: R2.1, U2.5 (SR)
unnamed: R3.2, U3.3 (INH)
unnamed: R4.1, U3.5 (SR)
unnamed: R5.1, U2.2 (IN)
unnamed: R6.1, U3.2 (IN)
unnamed: R9.2, SW1.3 (C)
unnamed: R12.1, U2.6 (IS)
unnamed: R13.1, U3.6 (IS)
unnamed: R14.2, U5.6 (IS)
unnamed: R15.2, U6.6 (IS)
unnamed: R16.1, U5.2 (IN)
unnamed: R17.1, U6.2 (IN)
unnamed: R18.2, U4.35 (TXD0/IO1)
unnamed: R19.2, U4.34 (RXD0/IO3)
unnamed: R20.1, U5.3 (INH)
unnamed: R21.2, U5.5 (SR)
unnamed: R22.1, U6.3 (INH)
unnamed: R23.1, U6.5 (SR)
unnamed: R29.2, U8.9 (AD0/MISO)
unnamed: R30.1, U8.22 (~CS)
unnamed: R31.2, U8.11 (FSYNC)
unnamed: R34.1, U9.3 (IO2), U9.7 (IO3)
PWM1: F1.2, Q3.1, R26.2, U4.24 (IO2)
PWM2: F2.2, Q5.1, R33.2, U4.26 (IO4)
RX: Button1.2, R18.1
Reset: Button1.5, U4.3 (EN)
S0: Sensor1.3, U4.8 (IO32)
S1: Sensor1.4, U4.16 (IO13)
S2: Sensor1.5, U4.13 (IO14)
S3: Sensor1.6, U4.23 (IO15)
SCL: Button1.6, R27.1, U4.36 (IO22), U8.23 (SCL/SCLK)
SDA: Button1.7, R28.1, U4.33 (IO21), U8.24 (SDA/MOSI)
TX: Button1.3, R19.1

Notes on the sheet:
Fan & Motor DC
ESP32
Encoder
Motor Driver
Ganti ADC Pin
Motor Connector
Baterai & Pengaman
Power Supply 2
Power Supply
Power Flag
MAINBOARD V3.1
Button & Sensor
MPU-9250
External Flash

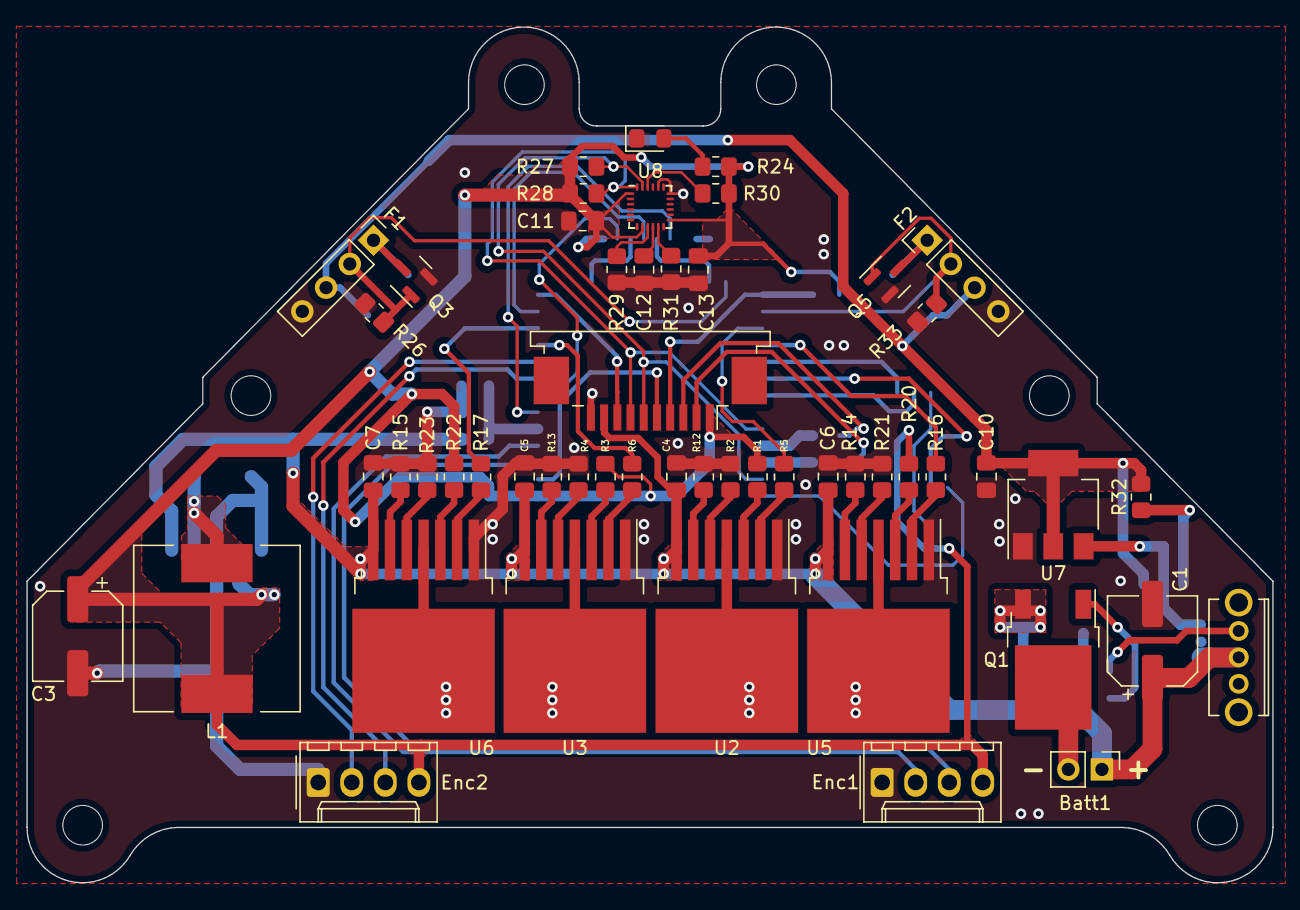
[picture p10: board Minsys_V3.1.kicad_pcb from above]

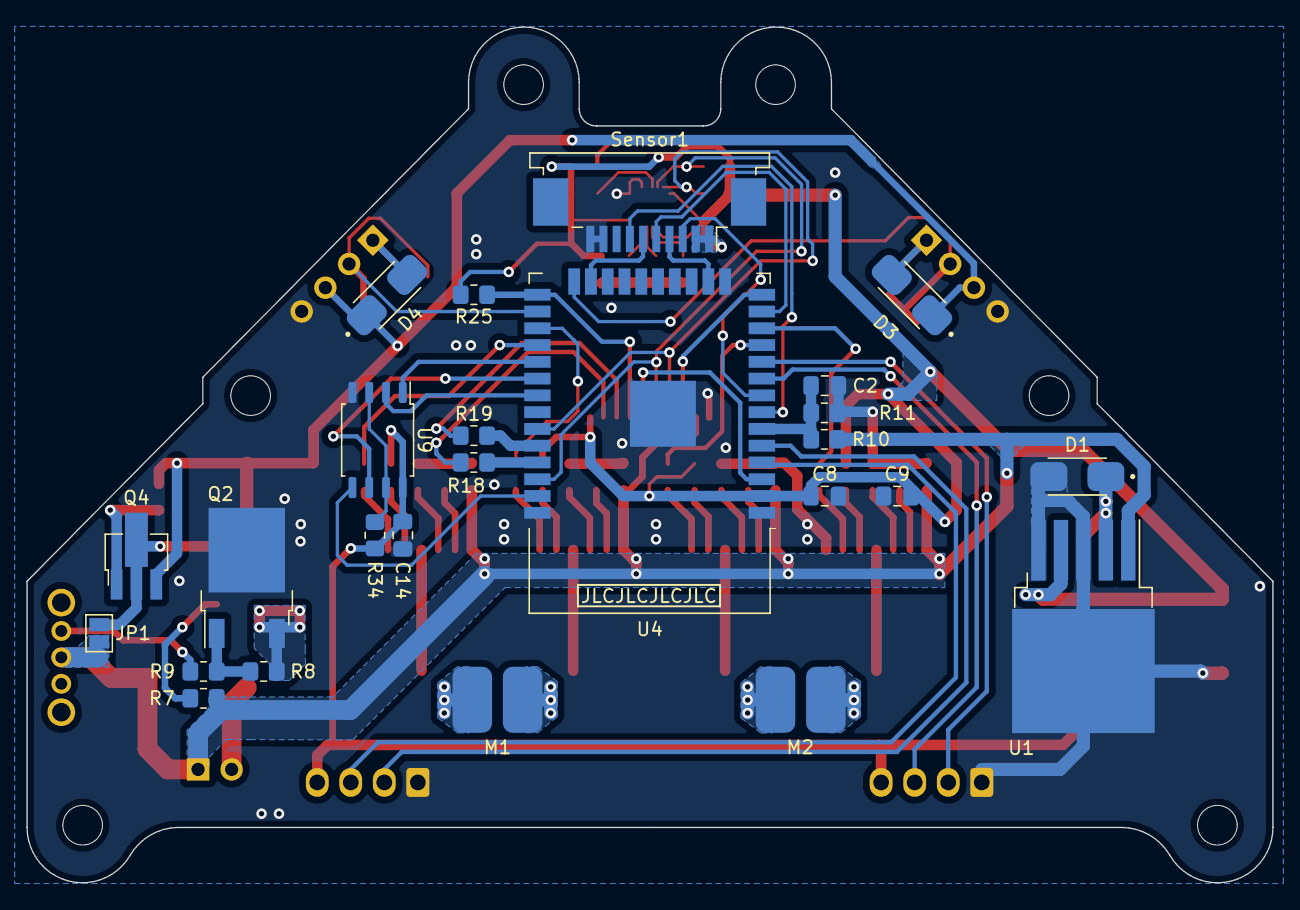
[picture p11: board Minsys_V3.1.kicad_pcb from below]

Board: 2 copper layers, 94.3 x 64.8 mm, 84 parts (26 on the bottom side), 69 nets.

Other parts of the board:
H1, H2, H2#2, H2#3, H2#4, H2#5: MountingHole; MountingHole_3mm

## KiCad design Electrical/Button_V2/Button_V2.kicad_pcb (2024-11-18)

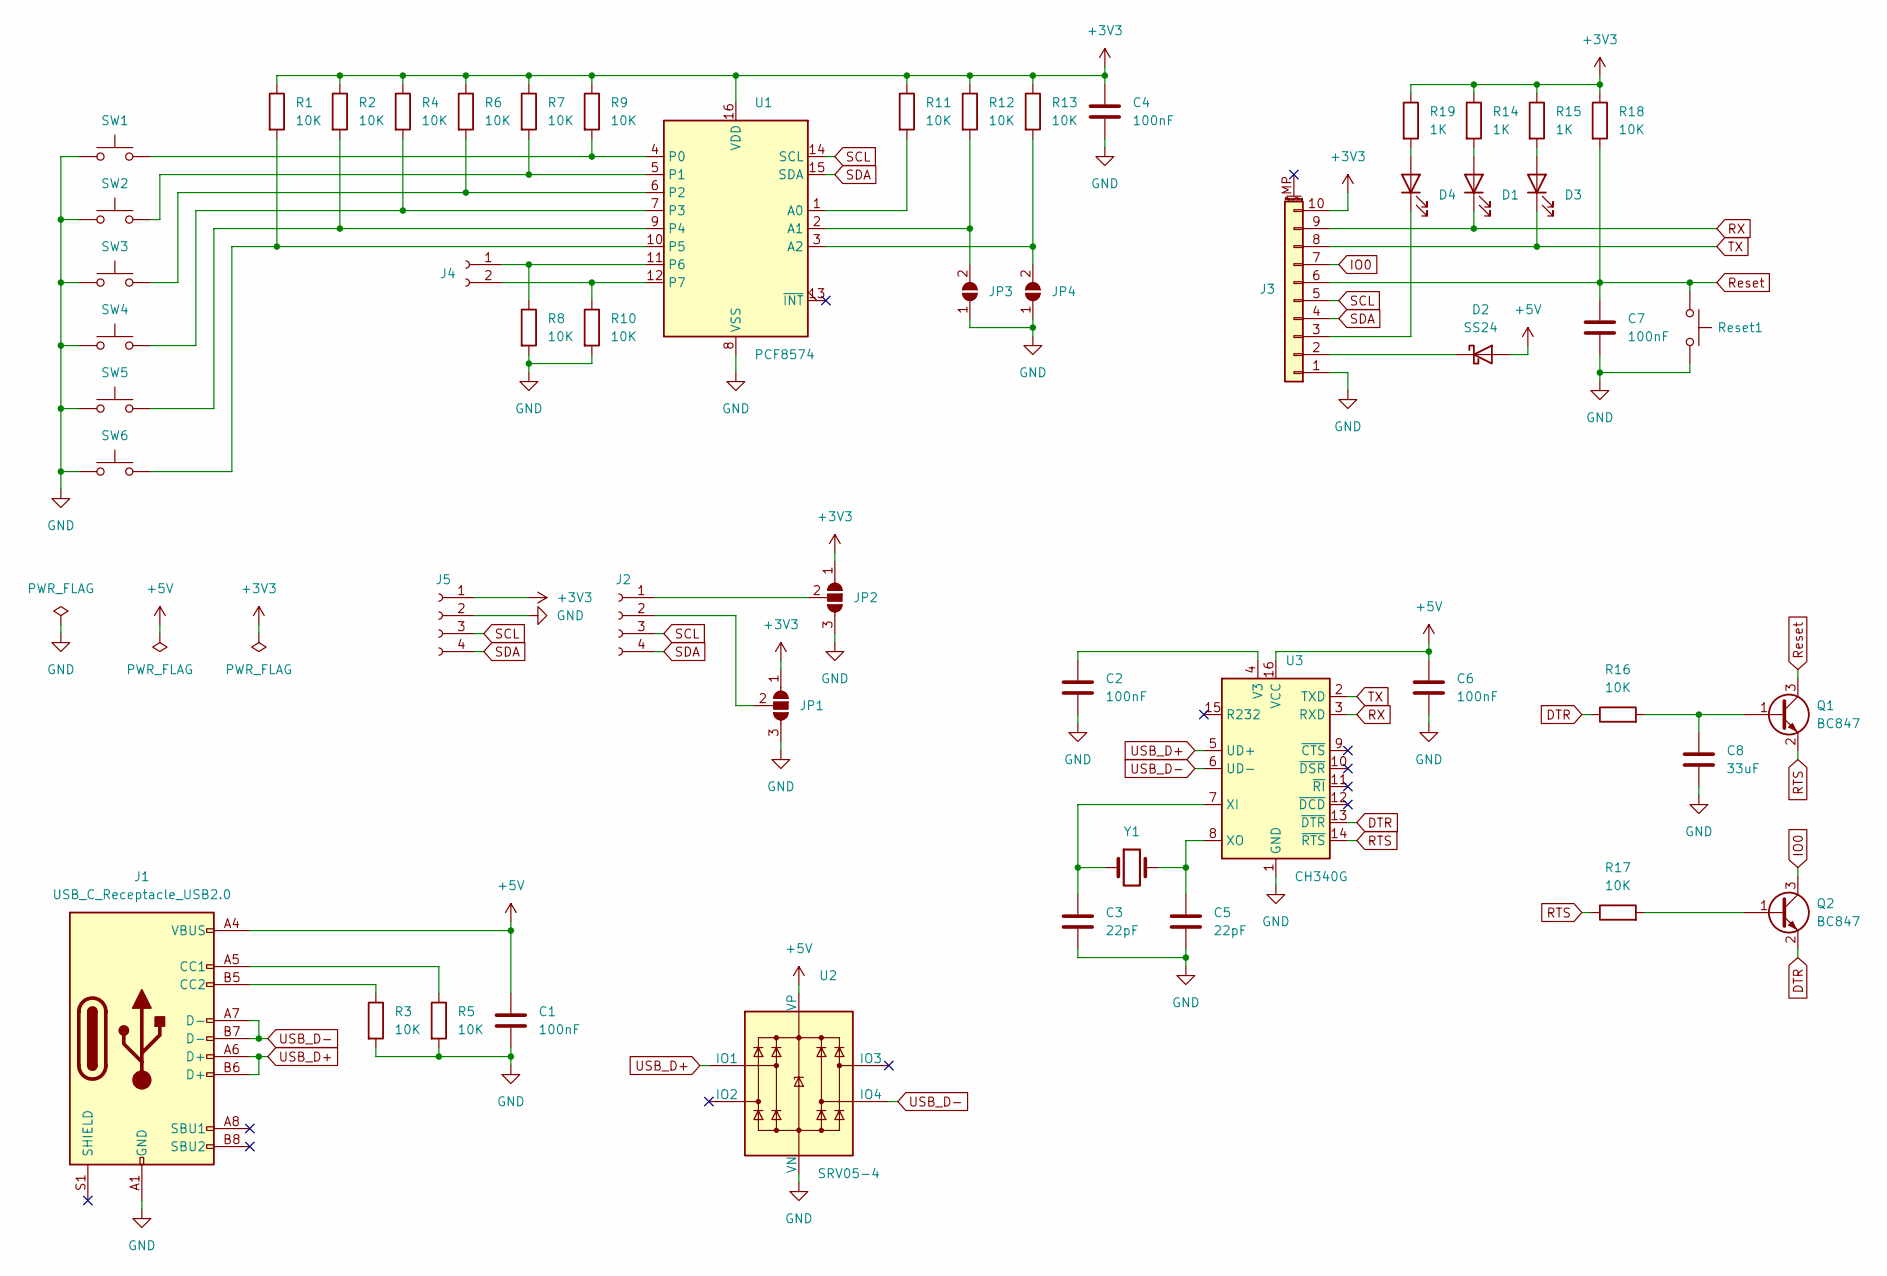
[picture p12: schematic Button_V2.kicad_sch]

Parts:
C1, C2, C4, C6, C7: 100nF; C_0805_2012Metric_Pad1.18x1.45mm_HandSolder
C3, C5: 22pF; C_0805_2012Metric_Pad1.18x1.45mm_HandSolder
C8: 33uF; C_0805_2012Metric_Pad1.18x1.45mm_HandSolder
D1, D3, D4: LED; LED_0805_2012Metric_Pad1.15x1.40mm_HandSolder
D2: SS24; DO_214
J1: USB_C_Receptacle_USB2.0; USB_C_Receptacle_HRO_TYPE-C-31-M-12
J2: Conn_01x04_Female; PinHeader_1x04_P2.54mm_Vertical
J3: Conn_01x10_MountingPin; TE_1-84952-0_1x10-1MP_P1.0mm_Horizontal
J4: Conn_01x02_Female; PinHeader_1x02_P2.54mm_Vertical
J5: Conn_01x04_Female
JP1, JP2: SolderJumper_3_Open; SolderJumper-3_P1.3mm_Open_RoundedPad1.0x1.5mm_NumberLabels
JP3, JP4: SolderJumper_2_Open; SolderJumper-2_P1.3mm_Open_TrianglePad1.0x1.5mm
Q1, Q2: BC847; SOT-23
R1, R2, R3, R4, R5, R6, R7, R8, R9, R10, R11, R12, R13, R16, R17, R18: 10K; R_0805_2012Metric_Pad1.20x1.40mm_HandSolder
R14, R15, R19: 1K; R_0805_2012Metric_Pad1.20x1.40mm_HandSolder
Reset1: SW_Push; Silent_Button
SW1, SW2, SW3, SW4, SW5, SW6: SW_Push; Silent_Button
U1: PCF8574; SOIC-16W_7.5x10.3mm_P1.27mm
U2: SRV05-4; SOT-23-6
U3: CH340G; SOIC-16_3.9x9.9mm_P1.27mm
Y1: Crystal; Crystal_SMD_HC49-SD

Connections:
+3V3: C4.1, J3.10, J5.1, JP1.1 (A), JP2.1 (A), R1.1, R2.1, R4.1, R6.1, R7.1, R9.1, R11.1, R12.1, R13.1, R14.1, R15.1, R18.1, R19.1, U1.16 (VDD)
+5V: C1.1, C6.1, D2.2 (A), J1.A4 (VBUS), J1.A9 (VBUS), J1.B4 (VBUS), J1.B9 (VBUS), U2.5 (VP), U3.16 (VCC)
DTR: Q2.2 (E), R16.1, U3.13 (~DTR)
GND: C1.2, C2.2, C3.2, C4.2, C5.2, C6.2, C7.2, C8.2, J1.A1 (GND), J1.A12 (GND), J1.B1 (GND), J1.B12 (GND), J3.1, J5.2, JP1.3 (B), JP2.3 (B), JP3.1 (A), JP4.1 (A), R3.2, R5.2, R8.2, R10.2, Reset1.2, SW1.1, SW2.1, SW3.1, SW4.1, SW5.1, SW6.1, U1.8 (VSS), U2.2 (VN), U3.1 (GND)
IO0: J3.7, Q2.3 (C)
unnamed: C2.1, U3.4 (V3)
unnamed: C3.1, U3.7 (XI), Y1.1
unnamed: C5.1, U3.8 (XO), Y1.2
unnamed: C8.1, Q1.1 (B), R16.2
unnamed: D1.2 (A), R14.2
unnamed: D2.1 (K), J3.2
unnamed: D3.2 (A), R15.2
unnamed: D4.1 (K), J3.3
unnamed: D4.2 (A), R19.2
unnamed: J1.A5 (CC1), R5.1
unnamed: J1.B5 (CC2), R3.1
unnamed: J2.1, JP2.2 (C)
unnamed: J2.2, JP1.2 (C)
unnamed: J4.1, R8.1, U1.11 (P6)
unnamed: J4.2, R10.1, U1.12 (P7)
unnamed: JP3.2 (B), R12.2, U1.2 (A1)
unnamed: JP4.2 (B), R13.2, U1.3 (A2)
unnamed: Q2.1 (B), R17.2
unnamed: R1.2, SW6.2, U1.10 (P5)
unnamed: R2.2, SW5.2, U1.9 (P4)
unnamed: R4.2, SW4.2, U1.7 (P3)
unnamed: R6.2, SW3.2, U1.6 (P2)
unnamed: R7.2, SW2.2, U1.5 (P1)
unnamed: R9.2, SW1.2, U1.4 (P0)
unnamed: R11.2, U1.1 (A0)
RTS: Q1.2 (E), R17.1, U3.14 (~RTS)
RX: D1.1 (K), J3.9, U3.3 (RXD)
Reset: C7.1, J3.6, Q1.3 (C), R18.2, Reset1.1
SCL: J2.3, J3.5, J5.3, U1.14 (SCL)
SDA: J2.4, J3.4, J5.4, U1.15 (SDA)
TX: D3.1 (K), J3.8, U3.2 (TXD)
USB_D+: J1.A6 (D+), J1.B6 (D+), U2.1 (IO1), U3.5 (UD+)
USB_D-: J1.A7 (D-), J1.B7 (D-), U2.6 (IO4), U3.6 (UD-)

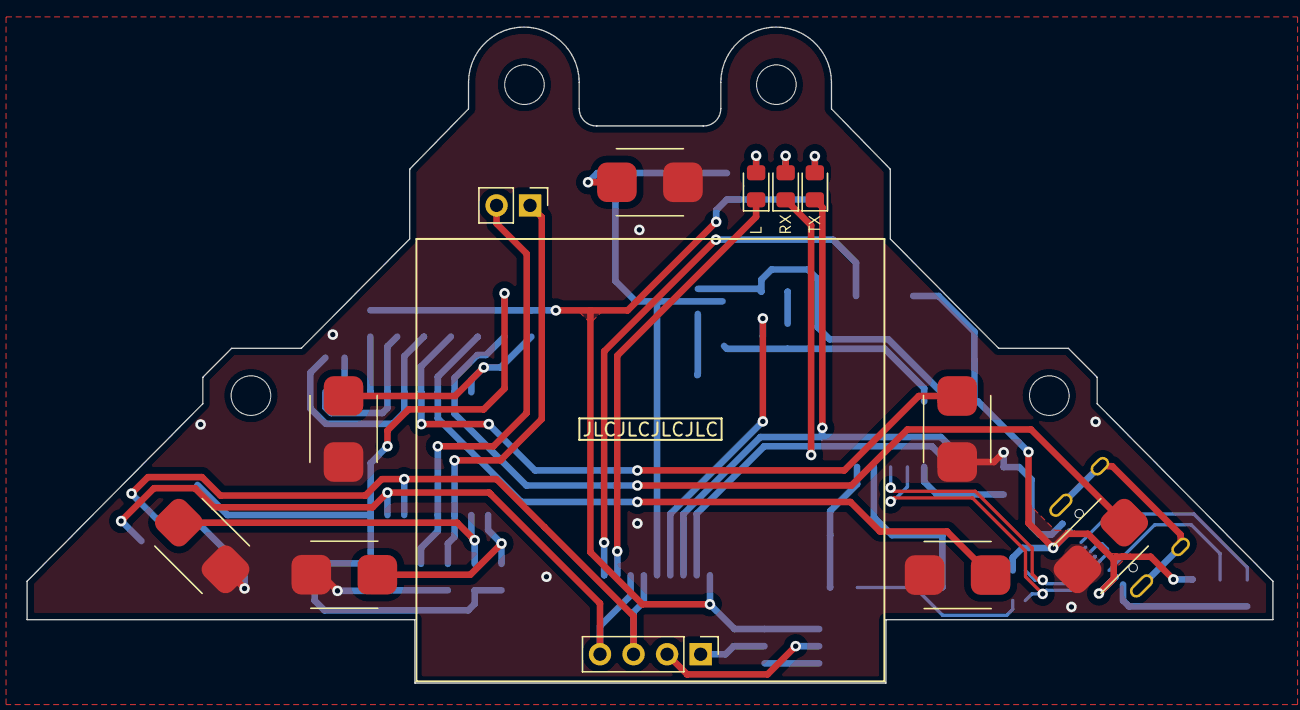
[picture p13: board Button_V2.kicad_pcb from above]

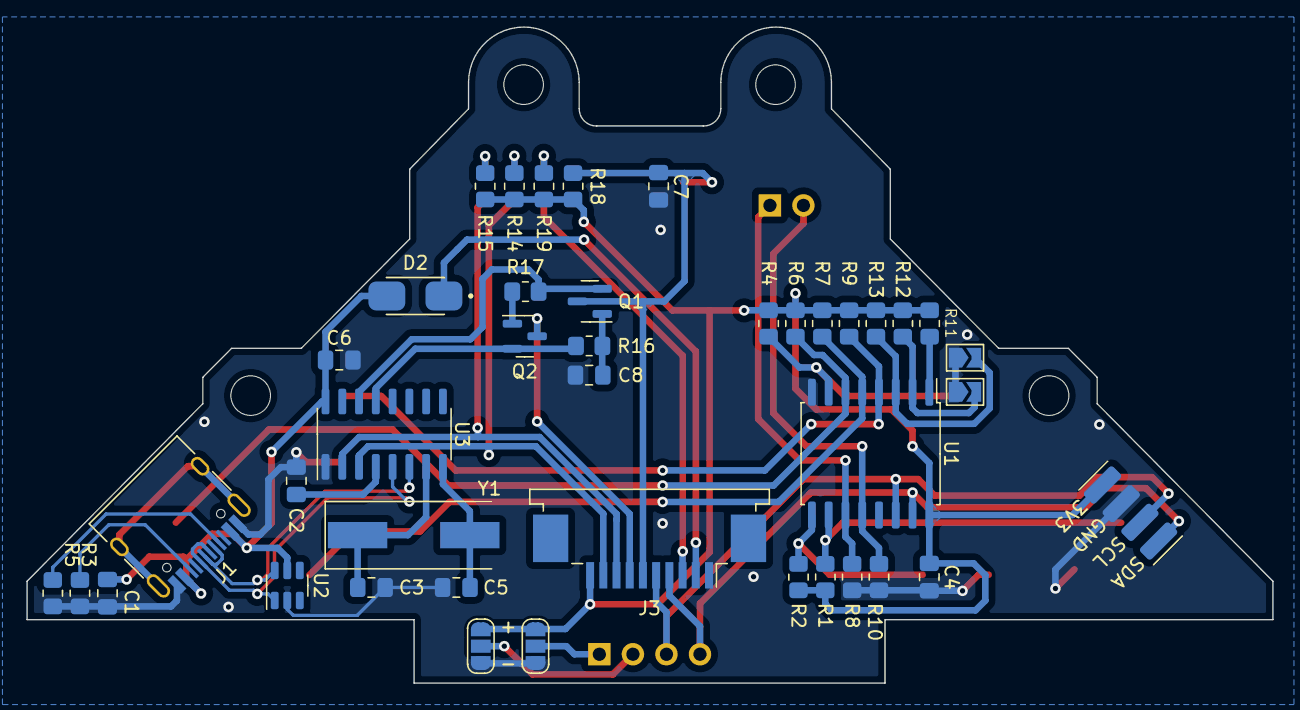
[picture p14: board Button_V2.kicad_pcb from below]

Board: 2 copper layers, 94.3 x 49.7 mm, 57 parts (41 on the bottom side), 38 nets.

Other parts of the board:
H1, H2, H2#2, H2#3: MountingHole; MountingHole_3mm

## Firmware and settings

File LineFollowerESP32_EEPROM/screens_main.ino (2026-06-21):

// ===========================================================================
// Layar: Home, Main Menu, Settings, Throttle, Set Default, Race Result.
// Semua non-blocking: handleX() = logika, renderX() = gambar (1 frame).
// ===========================================================================

//================================ HOME ==================================
void handleHome() {
  if (btnPressed(BTN_UP))   { if (--stHome.sel < 0) stHome.sel = 4; }
  if (btnPressed(BTN_DOWN)) { if (++stHome.sel > 4) stHome.sel = 0; }

  switch (stHome.sel) {
    case 0: // mode C(race) / F(tune)
      if (btnPressed(BTN_PLUS)) stHome.race = true;
      if (btnPressed(BTN_MIN))  stHome.race = false;
      if (btnPressed(BTN_OK))   pushScreen(SCR_MENU);
      break;
    case 1: // pilih plan
      if (btnRepeat(BTN_PLUS)) { if (++plan >= VAL_PLAN) plan = 0; saveHome(); }
      if (btnRepeat(BTN_MIN))  { plan = (plan == 0) ? VAL_PLAN - 1 : plan - 1; saveHome(); }
      if (btnPressed(BTN_OK))  pushScreen(SCR_SETINDEX);
      break;
    case 2: // normal speed
      if (btnRepeat(BTN_PLUS)) { if (normalSpeed <= 250) normalSpeed += 5; saveHome(); }
      if (btnRepeat(BTN_MIN))  { if (normalSpeed >= 5)   normalSpeed -= 5; saveHome(); }
      break;
    case 3: if (btnPressed(BTN_OK)) pushScreen(SCR_CHECKPOINT); break;
    case 4: if (btnPressed(BTN_OK)) pushScreen(SCR_CALIB);      break;
  }

  if (btnPressed(BTN_BACK)) {              // RUN = mulai
    if (stHome.race) { if (readBattery() >= minBat) runRace(); }
    else             pushScreen(SCR_TUNEPID);
  }
}

void renderHome() {
  headUp(false, false);
  displaySensor(readSensor());

  // Mode C/F
  if (stHome.sel == 0) lcd.fillRoundRect(48, 30, 30, 30, 5, SH110X_WHITE);
  else                 lcd.drawRoundRect(48, 30, 30, 30, 5, SH110X_WHITE);
  lcd_char(3, 56, 35, stHome.race ? "C" : "F", stHome.sel != 0, false, false);

  // SetP
  if (stHome.sel == 1) lcd.fillRoundRect(-5, 27, 45, 20, 3, SH110X_WHITE);
  else                 lcd.drawRoundRect(-5, 27, 45, 20, 3, SH110X_WHITE);
  sprintf(buff, "SetP:%d", plan + 1);
  lcd_char(1, 1, 31, buff, stHome.sel != 1, false, false);

  // Ns
  if (stHome.sel == 2) lcd.fillRoundRect(-5, 42, 45, 20, 3, SH110X_WHITE);
  else                 lcd.drawRoundRect(-5, 42, 45, 20, 3, SH110X_WHITE);
  sprintf(buff, "Ns:%03d", normalSpeed);
  lcd_char(1, 1, 51, buff, stHome.sel != 2, false, false);

  // CALSEN
  if (stHome.sel == 4) lcd.fillRoundRect(87, 27, 45, 20, 3, SH110X_WHITE);
  else                 lcd.drawRoundRect(87, 27, 45, 20, 3, SH110X_WHITE);
  lcd_char(1, 90, 31, "CALSEN", stHome.sel != 4, false, false);

  // CHKPNT
  if (stHome.sel == 3) lcd.fillRoundRect(87, 42, 45, 20, 3, SH110X_WHITE);
  else                 lcd.drawRoundRect(87, 42, 45, 20, 3, SH110X_WHITE);
  lcd_char(1, 90, 51, "CHKPNT", stHome.sel != 3, false, false);
}

//================================ MENU ==================================
// 0 Set Plan · 1 Calib · 2 Tune PID · 3 Test Motor · 4 Copy/Mirror · 5 Delete · 6 Settings
void handleMenu() {
  if (btnPressed(BTN_UP))   { if (--stMenu.sel < 0) stMenu.sel = 6; }
  if (btnPressed(BTN_DOWN)) { if (++stMenu.sel > 6) stMenu.sel = 0; }
  if (btnPressed(BTN_BACK)) { saveAll(); popScreen(); return; }

  switch (stMenu.sel) {
    case 0:
      if (btnRepeat(BTN_PLUS)) { if (++plan >= VAL_PLAN) plan = 0; }
      if (btnRepeat(BTN_MIN))  { plan = (plan == 0) ? VAL_PLAN - 1 : plan - 1; }
      if (btnPressed(BTN_OK))  pushScreen(SCR_SETINDEX);
      break;
    case 1:
      if (btnPressed(BTN_PLUS)) pushScreen(SCR_CALIB_AUTO);
      if (btnPressed(BTN_MIN))  pushScreen(SCR_CALIB_MANUAL);
      break;
    case 2: if (btnPressed(BTN_OK)) pushScreen(SCR_TUNEPID);    break;
    case 3: if (btnPressed(BTN_OK)) pushScreen(SCR_TESTMOTOR);  break;
    case 4: if (btnPressed(BTN_OK)) pushScreen(SCR_COPYMIRROR); break;
    case 5:
      if (btnRepeat(BTN_PLUS)) { if (++plan >= VAL_PLAN) plan = 0; }
      if (btnRepeat(BTN_MIN))  { plan = (plan == 0) ? VAL_PLAN - 1 : plan - 1; }
      if (btnPressed(BTN_OK))  { stReset.target = plan; pushScreen(SCR_RESETPLAN); }
      break;
    case 6: if (btnPressed(BTN_OK)) pushScreen(SCR_SETTINGS); break;
  }
}

void renderMenu() {
  const char* titles[7] = { "Set Plan", "Calib Sensor", "Tuning PID",
                            "Test Motor", "Copy Mirror Plan", "Delete Plan", "Settings" };
  switch (stMenu.sel) {
    case 0: lcd.drawBitmap(0, 5, logoSetPlan,         128, 64, SH110X_WHITE); break;
    case 1: lcd.drawBitmap(0, 5, logoCalibSensor,     128, 64, SH110X_WHITE); break;
    case 2: lcd.drawBitmap(0, 0, logoTunePID,         128, 64, SH110X_WHITE); break;
    case 3: lcd.drawBitmap(0, 0, logoTestMotor,       128, 64, SH110X_WHITE); break;
    case 4: lcd.drawBitmap(0, 0, logoCopyMirrorPlan,  128, 64, SH110X_WHITE); break;
    case 5: lcd.drawBitmap(0, 0, logoDeletePlan,      128, 64, SH110X_WHITE); break;
    case 6: lcd.drawBitmap(0, 0, logoSettings,        128, 64, SH110X_WHITE); break;
  }
  lcd_char(1, 18, 5, titles[stMenu.sel], true, false, false);

  if (stMenu.sel == 0 || stMenu.sel == 5) { sprintf(buff, "P%d", plan + 1); lcd_char(3, 78, 25, buff, true, false, false); }
  if (stMenu.sel == 1) { lcd_char(1, 70, 28, "+:Auto", true, false, false); lcd_char(1, 70, 42, "-:Manual", true, false, false); }

  // scrollbar
  lcd.drawRoundRect(124, 0, 3, 56, 1, SH110X_WHITE);
  lcd.fillRoundRect(124, 2 + stMenu.sel * 7, 3, 6, 1, SH110X_WHITE);
}

//============================== SETTINGS ================================
// hanya fitur yang benar-benar jalan: Set Default & Set Throttle.
void handleSettings() {
  if (btnPressed(BTN_UP))   { if (--stSettings.sel < 0) stSettings.sel = 1; }
  if (btnPressed(BTN_DOWN)) { if (++stSettings.sel > 1) stSettings.sel = 0; }
  if (btnPressed(BTN_BACK)) { saveAll(); popScreen(); return; }
  if (btnPressed(BTN_OK)) {
    if (stSettings.sel == 0) pushScreen(SCR_SETDEFAULT);
    else                     pushScreen(SCR_THROTTLE);
  }
}

void renderSettings() {
  lcd_char(1, 25, 2, "SETTINGS", true, false, false);
  lcd.drawLine(0, 12, 128, 12, SH110X_WHITE);
  const char* items[2] = { "Set Default", "Set Throttle" };
  for (int i = 0; i < 2; i++) {
    if (i == stSettings.sel) { lcd.fillRoundRect(4, 20 + i * 16, 120, 13, 2, SH110X_WHITE);
                               lcd_char(1, 10, 23 + i * 16, items[i], false, false, false); }
    else                       lcd_char(1, 10, 23 + i * 16, items[i], true, false, false);
  }
}

//============================== THROTTLE ================================
void handleThrottle() {
  if (btnPressed(BTN_UP) || btnPressed(BTN_DOWN)) stThrottle.sel = !stThrottle.sel;
  if (stThrottle.sel == 0) {
    if (btnRepeat(BTN_PLUS)) { if (++accelTA > 25) accelTA = 1; }
    if (btnRepeat(BTN_MIN))  { if (--accelTA == 0) accelTA = 25; }
  } else {
    if (btnRepeat(BTN_PLUS)) { if (++accelTB > 25) accelTB = 1; }
    if (btnRepeat(BTN_MIN))  { if (--accelTB == 0) accelTB = 25; }
  }
  if (btnPressed(BTN_BACK)) { saveAccel(); popScreen(); return; }
}

void renderThrottle() {
  lcd_char(1, 5, 2, "Set Throttle", true, false, false);
  lcd.drawLine(0, 12, 128, 12, SH110X_WHITE);
  sprintf(buff, "AccTA: %2d", accelTA);
  if (stThrottle.sel == 0) { lcd.fillRoundRect(10, 22, 108, 14, 2, SH110X_WHITE); lcd_char(1, 16, 26, buff, false, false, false); }
  else                       lcd_char(1, 16, 26, buff, true, false, false);
  sprintf(buff, "AccTB: %2d", accelTB);
  if (stThrottle.sel == 1) { lcd.fillRoundRect(10, 40, 108, 14, 2, SH110X_WHITE); lcd_char(1, 16, 44, buff, false, false, false); }
  else                       lcd_char(1, 16, 44, buff, true, false, false);
}

//============================ SET DEFAULT ===============================
void handleSetDefault() {
  if (stSetDef.step == 0) {
    if (btnPressed(BTN_UP) || btnPressed(BTN_DOWN)) stSetDef.yes = !stSetDef.yes;
    if (btnPressed(BTN_OK))   { if (stSetDef.yes) stSetDef.step = 1; else popScreen(); return; }
    if (btnPressed(BTN_BACK)) { popScreen(); return; }
  } else if (stSetDef.step == 1) {
    for (byte p = 0; p < VAL_PLAN; p++) {
      resetOnePlan(p);
      for (byte i = 0; i < VAL_CHECKP; i++) { cpAct[p][i] = cpDelay[p][i] = cpTimerA[p][i] = cpReadIdx[p][i] = 0; }
    }
    plan = 0; normalSpeed = 80; stopIndex = 0; countCP = 0;
    saveHome(); saveAll();
    stSetDef.step = 2;
  } else {
    if (btnPressed(BTN_OK) || btnPressed(BTN_BACK)) { popScreen(); return; }
  }
}

void renderSetDefault() {
  if (stSetDef.step == 2) { lcd_char(1, 35, 28, "Selesai!", true, false, false); return; }
  lcd_char(1, 15, 12, "Set Default Robot?", true, false, false);
  if (!stSetDef.yes) { lcd.fillRoundRect(16, 32, 30, 14, 2, SH110X_WHITE); lcd_char(1, 22, 36, "No", false, false, false); lcd_char(1, 78, 36, "Yes", true, false, false); }
  else               { lcd.fillRoundRect(74, 32, 34, 14, 2, SH110X_WHITE); lcd_char(1, 22, 36, "No", true, false, false);  lcd_char(1, 80, 36, "Yes", false, false, false); }
}

//============================ RACE RESULT ===============================
void handleRaceResult() {
  if (btnPressed(BTN_OK) || btnPressed(BTN_BACK)) setScreen(SCR_HOME);
}

void renderRaceResult() {
  headUp(false, false);
  sprintf(buff, "Stop : %d", stResult.stopIdx);
  lcd_char(1, 5, 18, buff, true, false, false);
  sprintf(buff, "TIME : %.3f s", stResult.elapsed);
  lcd_char(1, 5, 30, buff, true, false, false);
  lcd_char(1, 5, 46, "Tekan OK / RUN", true, false, false);
}

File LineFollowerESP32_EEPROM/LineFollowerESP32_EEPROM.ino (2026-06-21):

// ===========================================================================
// Robot Line Follower ESP32 — EEPROM Polinema
// Arsitektur NON-BLOCKING (cooperative): loop() = input -> handle -> render.
// Kompatibel Arduino-ESP32 core v3.x.
// ===========================================================================

#include "oled.h"     // display SH1106 + bitmap + helper gambar
#include "input.h"    // tombol non-blocking (PCF8574)
#include "encoder.h"
#include "motor.h"    // LEDC v3.x
#include "sensor.h"
#include "PID.h"
#include "data.h"     // konfigurasi + plan + checkpoint + lookup
#include "timer.h"    // StopWatch
#include "ui.h"       // state machine layar

#define FRAME_MS 33                 // ~30 fps render
static unsigned long lastFrame = 0;

void setup() {
  Wire.begin();
  initDisplay();
  setCpuFrequencyMhz(240);
  initEncoder(0);
  setupSensor();
  initMotor();
  initInput();
  setupStorage();
  delay(100);
  oledClear();
  enterScreen(SCR_HOME);
}

void loop() {
  inputUpdate();                    // baca tombol sekali per frame (non-blocking)
  uiHandle();                       // logika layar aktif
  if (millis() - lastFrame >= FRAME_MS) {
    lastFrame = millis();
    uiRender();                     // satu lcd.display() per frame
  }
}

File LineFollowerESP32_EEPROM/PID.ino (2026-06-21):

// ===========================================================================
// Kontrol PID line follower.
// program(): pola sensor -> error (lookup), hitung PID, perintah motor.
//   mode : 0=center, 1=right, 2=left   (Follow Line Mode)
//   mask : 0=semua, 1..3 = abaikan 1..3 sensor tiap sisi (Used Sensor)
// Logika & tabel dipertahankan dari versi asli (sudah teruji di lintasan).
// ===========================================================================

void program(int dataSensor, byte mode, int speed, byte pid, byte mask) {

  if      (mask == 1) dataSensor = dataSensor & 0b01111111111110;
  else if (mask == 2) dataSensor = dataSensor & 0b00111111111100;
  else if (mask == 3) dataSensor = dataSensor & 0b00011111111000;

  switch (mode) {
    case 0: // center
      switch (dataSensor) {
        // WHITE LINE
        case 0b11111111111110: error = -13; break;
        case 0b11111111111100: error = -12; break;
        case 0b11111111111101: error = -13; break;
        case 0b11111111111001: error = -11; break;
        case 0b11111111111011: error = -10; break;
        case 0b11111111110011: error = -8;  break;
        case 0b11111111110111: error = -7;  break;
        case 0b11111111100111: error = -6;  break;
        case 0b11111111101111: error = -5;  break;
        case 0b11111111001111: error = -4;  break;
        case 0b11111111011111: error = -3;  break;
        case 0b11111110011111: error = -2;  break;
        case 0b11111110111111: error = -1;  break;
        case 0b11111100111111: error = 0;   break;
        case 0b11111101111111: error = 1;   break;
        case 0b11111001111111: error = 2;   break;
        case 0b11111011111111: error = 3;   break;
        case 0b11110011111111: error = 4;   break;
        case 0b11110111111111: error = 5;   break;
        case 0b11100111111111: error = 6;   break;
        case 0b11101111111111: error = 7;   break;
        case 0b11001111111111: error = 8;   break;
        case 0b11011111111111: error = 10;  break;
        case 0b10011111111111: error = 11;  break;
        case 0b10111111111111: error = 13;  break;
        case 0b00111111111111: error = 12;  break;
        case 0b01111111111111: error = 13;  break;
        // BLACK LINE - left
        case 0b00000000000111: error = -13; break;
        case 0b00000000001111: error = -12; break;
        case 0b00000000001110: error = -10; break;
        case 0b00000000011110: error = -8;  break;
        case 0b00000000011100: error = -7;  break;
        case 0b00000000111100: error = -6;  break;
        case 0b00000000111000: error = -5;  break;
        case 0b00000001111000: error = -4;  break;
        case 0b00000001110000: error = -3;  break;
        case 0b00000011110000: error = -2;  break;
        case 0b00000011100000: error = -1;  break;
        // BLACK LINE - right
        case 0b00000111000000: error = 1;   break;
        case 0b00001111000000: error = 2;   break;
        case 0b00001110000000: error = 3;   break;
        case 0b00011110000000: error = 4;   break;
        case 0b00011100000000: error = 5;   break;
        case 0b00111100000000: error = 6;   break;
        case 0b00111000000000: error = 7;   break;
        case 0b01111000000000: error = 8;   break;
        case 0b01110000000000: error = 10;  break;
        case 0b11110000000000: error = 12;  break;
        case 0b11100000000000: error = 13;  break;
        // BLACK LINE - single/narrow
        case 0b00000000000001: error = -13; break;
        case 0b00000000000011: error = -12; break;
        case 0b00000000000010: error = -11; break;
        case 0b00000000000110: error = -10; break;
        case 0b00000000000100: error = -9;  break;
        case 0b00000000001100: error = -8;  break;
        case 0b00000000001000: error = -7;  break;
        case 0b00000000011000: error = -6;  break;
        case 0b00000000010000: error = -5;  break;
        case 0b00000000110000: error = -4;  break;
        case 0b00000000100000: error = -3;  break;
        case 0b00000001100000: error = -2;  break;
        case 0b00000001000000: error = -1;  break;
        case 0b00000011000000: error = 0;   break;
        case 0b00000010000000: error = 1;   break;
        case 0b00000110000000: error = 2;   break;
        case 0b00000100000000: error = 3;   break;
        case 0b00001100000000: error = 4;   break;
        case 0b00001000000000: error = 5;   break;
        case 0b00011000000000: error = 6;   break;
        case 0b00010000000000: error = 7;   break;
        case 0b00110000000000: error = 8;   break;
        case 0b00100000000000: error = 9;   break;
        case 0b01100000000000: error = 10;  break;
        case 0b01000000000000: error = 11;  break;
        case 0b11000000000000: error = 12;  break;
        case 0b10000000000000: error = 13;  break;
      } break;

    case 1: // right
      switch (dataSensor) {
        case 0b00000000000001: error = -7;  break;
        case 0b00000000000011: error = -6;  break;
        case 0b00000000000010: error = -5;  break;
        case 0b00000000000110: error = -4;  break;
        case 0b00000000000100: error = -3;  break;
        case 0b00000000001100: error = -2;  break;
        case 0b00000000001000: error = -1;  break;
        case 0b00000000011000: error = 0;   break;
        case 0b00000000010000: error = 1;   break;
        case 0b00000000110000: error = 2;   break;
        case 0b00000000100000: error = 3;   break;
        case 0b00000001100000: error = 4;   break;
        case 0b00000001000000: error = 5;   break;
        case 0b00000011000000: error = 6;   break;
        case 0b00000010000000: error = 7;   break;
        case 0b00000110000000: error = 8;   break;
        case 0b00000100000000: error = 9;   break;
        case 0b00001100000000: error = 10;  break;
        case 0b00001000000000: error = 11;  break;
        case 0b00011000000000: error = 12;  break;
        case 0b00010000000000: error = 13;  break;
        case 0b00110000000000: error = 13;  break;
        case 0b00100000000000: error = 13;  break;
        case 0b01100000000000: error = 13;  break;
        case 0b01000000000000: error = 13;  break;
        case 0b11000000000000: error = 12;  break;
        case 0b10000000000000: error = 13;  break;
      } break;
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

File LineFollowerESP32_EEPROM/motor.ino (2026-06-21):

// ===========================================================================
// Motor driver (H-bridge BTS7960) — LEDC PWM, core v3.x.
// v2.x: ledcSetup(ch,..) + ledcAttachPin(pin,ch) + ledcWrite(ch,duty)
// v3.x: ledcAttach(pin, freq, res)            + ledcWrite(pin, duty)
// ===========================================================================

void initMotor() {
  ledcAttach(Motor1_A, FREQUENCY, RESOLUTION);
  ledcAttach(Motor1_B, FREQUENCY, RESOLUTION);
  ledcAttach(Motor2_A, FREQUENCY, RESOLUTION);
  ledcAttach(Motor2_B, FREQUENCY, RESOLUTION);
}

void pwmMotor(int pwm1, int pwm2) {   // pwm1 = kiri, pwm2 = kanan
  pwm1 = constrain(pwm1, -255, 255);
  pwm2 = constrain(pwm2, -255, 255);

  if (pwm1 >= 0) {
    ledcWrite(Motor1_A, pwm1);
    ledcWrite(Motor1_B, 0);
  } else {
    ledcWrite(Motor1_A, 0);
    ledcWrite(Motor1_B, -pwm1);
  }

  if (pwm2 >= 0) {
    ledcWrite(Motor2_A, pwm2);
    ledcWrite(Motor2_B, 0);
  } else {
    ledcWrite(Motor2_A, 0);
    ledcWrite(Motor2_B, -pwm2);
  }
}

void speedOne(int spd) { pwmMotor(spd, spd); }

void stopMotor() {
  ledcWrite(Motor1_A, 0);
  ledcWrite(Motor1_B, 0);
  ledcWrite(Motor2_A, 0);
  ledcWrite(Motor2_B, 0);
}

void stopMotorL() {
  ledcWrite(Motor1_A, 0);
  ledcWrite(Motor1_B, 0);
}

void stopMotorR() {
  ledcWrite(Motor2_A, 0);
  ledcWrite(Motor2_B, 0);
}

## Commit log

2024-08-07 Fix Sensor Bug with kalman filter
    - fix the PID
    [LineFollowerESP32_EEPROM.ino, PID.ino, data.h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]
2026-06-21 refactor: arsitektur UI non-blocking + migrasi Arduino-ESP32 core v3.x
    Rombak total lapisan UI/input/orkestrasi (lapisan kontrol PID/sensor/motor
    dipertahankan). Compile bersih: arduino-cli esp32:esp32 (0 error/warning,
    Flash 29%, RAM 13%).
    Arsitektur baru:
    - Input non-blocking (event PRESS/HOLD/RELEASE, debounce + auto-repeat millis)
    - Render 1x lcd.display per frame (~30 fps)
    - State machine layar + stack; state lokal per layar (hapus global bersama)
    - Race tetap loop real-time, abort non-blocking, timing berbasis millis()
    Migrasi v3.x:
    - LEDC: ledcSetup/ledcAttachPin/ledcWrite(ch) -> ledcAttach(pin)/ledcWrite(pin)
    Bug fix:
    - VAL_INDEX 50 -> 100 (perbaiki buffer overflow index 0-99)
    - M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
    [LineFollowerESP32_EEPROM.ino, PID.ino, data.h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]

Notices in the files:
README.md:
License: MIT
